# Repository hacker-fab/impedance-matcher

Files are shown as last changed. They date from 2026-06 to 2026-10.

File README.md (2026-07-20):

# Automated Impedance Matcher

Teensy 4.1 control loop firmware, custom PCB/CAD hardware, and Python telemetry logging/plotting tools.

## Layout

```
├── firmware/
│   ├── impedance_matcher/                 # Tuning loop, local UI, & motor controls
│   ├── headless_matcher/                  # Serial-only sketch
│   ├── live.py                            # Serial reader, live plots, CSV logger
│   └── plot.py                            # Offline plots & Mermaid export
└── hardware/
    ├── CAD/                               # Mechanical design & enclosure models
    └── PCB/                               # KiCad project & manufacturing files
        ├── impedance_matcher.kicad_pro    # KiCad project main file
        ├── spice/                         # SPICE verification of analog support circuits
        └── production/                    # JLCPCB manufacturing & assembly
            ├── imp_match.zip              # Gerbers
            ├── imp_match_bom.csv          # SMT BOM
            └── imp_match_positions.csv    # SMT CPL
```

**Arduino libraries:** Adafruit SSD1306, Adafruit GFX, and TMCStepper (GUI build); TMCStepper only for headless.

## Firmware

- **GUI:** Gradient-style matching toward lower VSWR; loop runs matching, encoder poll, then OLED refresh.
- **Headless:** Same matching; control via serial (`stream on`, `help`, etc.).

Serial is **500000** baud unless you change it in code and in `live.py`.

## Live telemetry

- Default CSV path is `data/csv/latest.csv`.
- Enable **`VSWR_CSV`** lines from the device: **USB log** in settings, or `stream on` in headless.

```bash
# From repo root; adjust --port to your Teensy
python firmware/live.py --port /dev/cu.usbmodemXXXX --window-seconds 20
```

## Offline plots

- Loads the 8-column telemetry CSV, drops bad/outlier rows, then plots VSWR, motors, and match state.
- **Matplotlib** is the default windowed plot.
- **Plotly:** `--interactive` (browser) or `--html`.
- **Mermaid:** `--mermaid` writes `data/mermaid/<csv_stem>_{vswr,motor1,motor2,match}.mmd`.
```bash
python firmware/plot.py path/to/run.csv
python firmware/plot.py path/to/run.csv --minutes --sample-interval 0.25
python firmware/plot.py path/to/run.csv --interactive
python firmware/plot.py path/to/run.csv --html
python firmware/plot.py path/to/run.csv --mermaid
```

## Telemetry CSV format

Written by `live.py` (and compatible with `plot.py`):

`host_time_s,device_millis,vswr,forward_v,reverse_v,motor1_pos_rad,motor2_pos_rad,at_match`

## Hardware notes

The analog support circuits (SWR sensing, input protection) were checked in ngspice.
See `hardware/PCB/spice/` for results and testbenches.

## Authors

- Miguel Salvacion
- William Gao

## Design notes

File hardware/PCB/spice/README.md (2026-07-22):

# SPICE Verification

ngspice checks on the board's analog support circuits: the SWR sense chain, the
input protection, and the 5 V -> 18 V -> 12 V power rail (DC). MCU, steppers,
OLED, fan, and opto are not simulated.

SWR path: `FWD_IN -> U1A buffer -> R10 2.7k / R13 1k divider -> ADC`, gain x0.27027
(TLV2372 on 12 V rail). REV path is identical (U1B, R11/R12).

## Results

### SWR -> ADC ceiling
Worst case is the buffer saturating near the 12 V rail. Ceiling lands at ~3.24 V
across every model, ~55 mV under the 3.3 V full scale. No clipping.

| Model | Ceiling  |
|---|---|
| Ideal buffer | 3.230 V  |
| Real TLV2372 macromodel | 3.243 V  |
| + PCB trace parasitics | 3.241 V  |

### Resistor tolerance (1% parts)
Worst-case divider ratio is +/-1.0% (R13 contributes (1-k)*1% = 0.73%, R10
contributes k*1% = 0.27%) -> ceiling ~3.27 V, still under 3.3 V.

### Protection
- Gate clamp (CR1 BZX84C5V6): off below 5 V; breaks down at 5.5 V and holds Vgs
  near -5.6 V up to 16 V input. Without it the gate would see -16 V.
- Reverse polarity (DMP6180 P-FET): reverse input blocked (rail ~nV, ~pA). Forward
  conducts with ~5 mV drop, ~120 mA at 12 V.

### PCB parasitics
SWR trace resistance is 0.05 - 0.10 ohm, via inductance ~0.7 nH (irrelevant at DC).
Shifts the ceiling by ~2.4 mV.

### SWR input protection
Each input has a 1k series resistor (R14/R15) plus clamp diodes to VCC/GND
(D2 BAV99S). This caps the TLV2372 input current on a fault, since
`I_clamp ~= (Vfault - Vrail - Vf) / 1k`. Abs-max is +/-10 mA.

| Fault on `FWD_IN` | unprotected | with R + clamp | vs +/-10 mA |
|---|---|---|---|
| 18 V | 1.02 A | 5.2 mA | safe |
| 30 V | 3.41 A | 17.1 mA | still over  |
| -5 V | 0.82 A | 4.2 mA | safe |

Normal operation is unaffected (8 V in -> 8.00 V pin) since the input draws no
DC. 30 V would need 2.2k (~7.9 mA).

### Power rail, DC
Rail is `5 V (USB) -> MT3608 boost -> ~17.5 V -> L7812 -> 12 V`. DC operating point
only; MT3608 switching ripple is out of scope.

- **LDO** (`ldo_reg.cir`): 18 -> 12 V holds 12.00 V across 0 - 1.2 A. `Pd =
  (Vin-Vout)*Iload` = 7.2 W at 1.2 A -- needs a heatsink (bare TO-220 ~2 W).
- **Chain** (`rail_chain_dc.cir`): `5 -> 17.51 -> 12.00 V` (R8 62k / R7 2.2k set the
  boost setpoint), lands 12.00 V on the TLV2372 VCC pin; SWR ADC reads 2.16 V for
  8 V `FWD_IN`.

Caveat: `l7812.lib` is behavioral (fixed 2 V dropout, no current limit); above
1.5 A is un-modeled.

## Testbenches

Run from this folder with `ngspice -b <file>.cir`. Batch mode writes sweep data to
the `.txt`/`.out` each file names (`wrdata`); DC-point benches `print` to stdout.

Install ngspice, or use the `ngspice` in KiCad's `bin/`. Results here are from
ngspice-46 (KiCad 10.0).

| File | Tests |
|---|---|
| `swr_opamp_chain.cir` | SWR buffer + divider sweep (ideal op-amp) |
| `opamp_fidelity.cir` | Same chain, real TLV2372 macromodel |
| `parasitic_ceiling.cir` | Chain with extracted PCB trace parasitics |
| `prot_gateclamp.cir` | Zener gate clamp sweep |
| `prot_revpol2.cir` | Reverse-polarity P-FET blocking + forward drop |
| `opamp_input_ov.cir` | SWR input overvoltage, pin clamp current |
| `opamp_input_protect.cir` | Series R + clamp fix, fault current <10mA |
| `ldo_reg.cir` | L7812 18->12V regulation, dropout, dissipation |
| `rail_chain_dc.cir` | End-to-end 5->18->12V DC, TLV2372 VCC |
| `l7812.lib` | L7812 behavioral reg model (included above) |
| `tlv2372.lib` | TLV2372 op-amp macromodel (included above) |

Outputs (`.txt`, `.out`, `.log`) are gitignored; re-run to regenerate.

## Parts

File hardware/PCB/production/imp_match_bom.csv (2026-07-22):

Designator | Footprint | Quantity | Value | LCSC Part #
A1 | TEENSY_LONG_EXT | 1 | TEENSY_4.1
C1, C2 | CAPC2012X110 | 2 | 22u | C45783
C10, C7, C8, C9 | CAPC2012X110 | 4 | 330n | C1740
C3, C4 | CAPPRD508W65D1000H1100B | 2 | 100u
CR1 | SOT95P240X110-3N | 1 | BZX84C5V6 | C148101
D1 | SMB_ONS | 1 | SS34 | C8678
D2 | SOT-363_SC-70-6 | 1 | BAV99S
DRIVER1, DRIVER2 | MODULE_TMC2209_SILENTSTEPSTICK | 2 | TMC2209_SILENTSTEPSTICK
FAN1, OLED1 | B4B-XH-A | 2 | Conn_01x04
FB1, FB2, FB3 | 0805 | 3 | FerriteBead | C15957
I2C1 | B2B-XH-A | 1 | Conn_01x02
L1 | INDM5450X580 | 1 | 22u | C9391
MOTOR1, MOTOR2 | JST-4-PTH-VERT | 2 | Conn_01x04
POWER1, TRANSMIT1 | 1X02_2.54_SCREWTERM | 2 | Conn_01x02
Q1 | DIP762W50P254L650H455Q4B | 1 | PC817 | C20612593
R1 | RESC2012X65 | 1 | 470 | C17710
R10, R11 | RESC2012X65 | 2 | 2.7k | C17530
R12, R13, R14, R15 | RESC2012X65 | 4 | 1k | C17513
R2, R5, R7 | RESC2012X65 | 3 | 2.2k | C17520
R3, R4, R6 | RESC2012X65 | 3 | 100k | C149504
R8 | RESC2012X65 | 1 | 62k | C17783
R9 | RESC2012X65 | 1 | 10k | C17414
REV_POLARITY1 | TO252_DMP6180SK3_DIO | 1 | DMP6180SK3-13TO252_DMP6180SK3_DIO | C93034
ROTARY1 | JST_B5B-XH-A | 1 | Conn_01x05
STEP_DOWN1 | TO-220-3 | 1 | L7812CV | C105651
STEP_UP0 | SOT95P280X145-6N | 1 | MT3608 | C84817
SWR1 | B3B-XH-A | 1 | JST_03
U1 | DIP794W45P254L959H508Q8 | 1 | TLV2372IP | C2878991

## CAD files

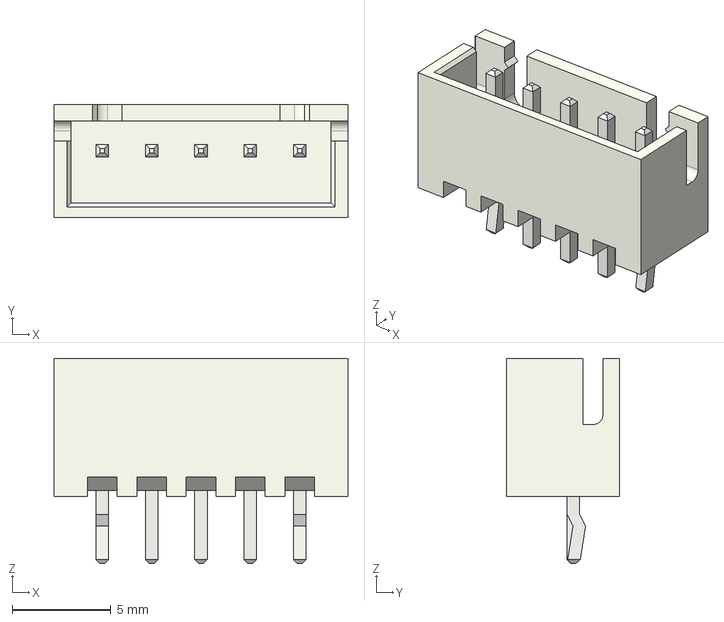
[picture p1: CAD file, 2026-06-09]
hardware/PCB/3dmodels/JST_XH_B5B-XH-A_1x05_P2.50mm_Vertical.step
14.9 x 5.75 x 10.4 mm

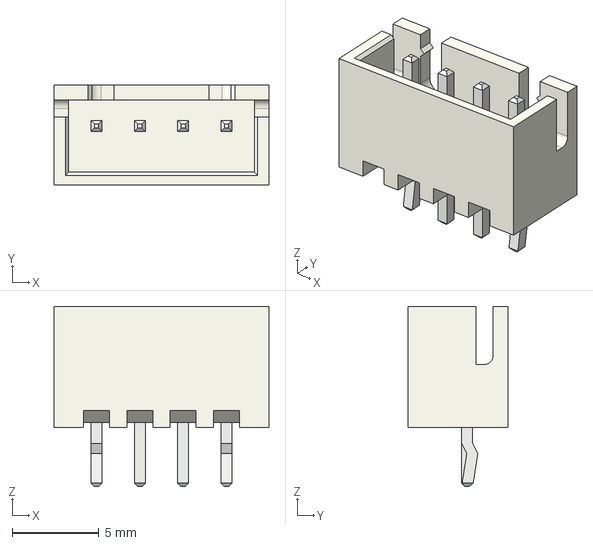
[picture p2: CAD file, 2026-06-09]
hardware/PCB/3dmodels/JST_XH_B4B-XH-A_1x04_P2.50mm_Vertical.step
12.4 x 5.75 x 10.4 mm

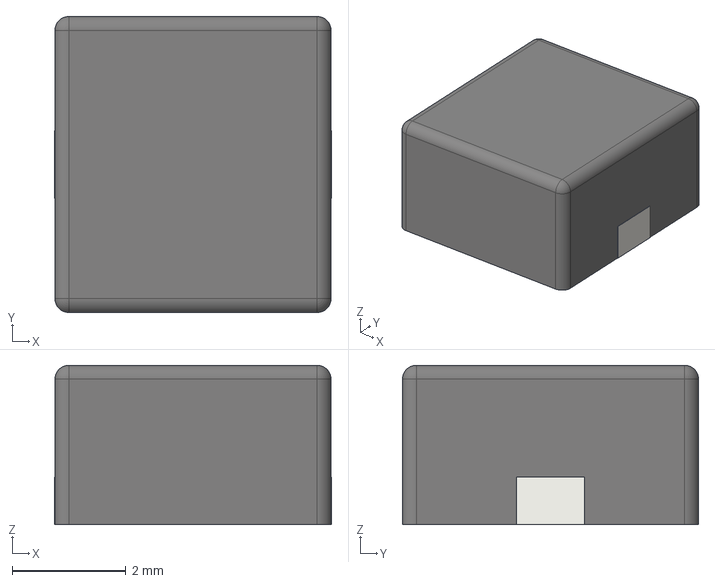
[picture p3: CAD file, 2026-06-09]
hardware/PCB/3dmodels/L_Changjiang_FXL0530.step
4.87 x 5.20 x 2.80 mm

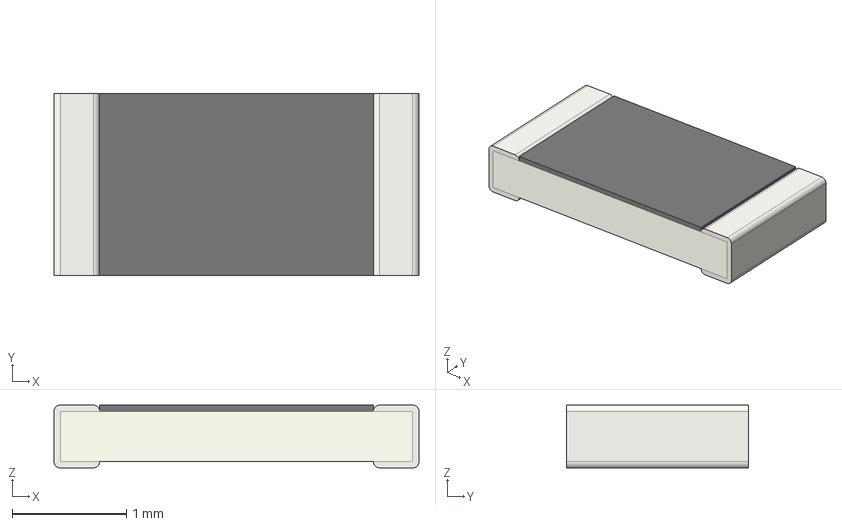
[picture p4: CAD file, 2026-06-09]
hardware/PCB/3dmodels/R_1206_3216Metric.step
3.20 x 1.60 x 0.55 mm

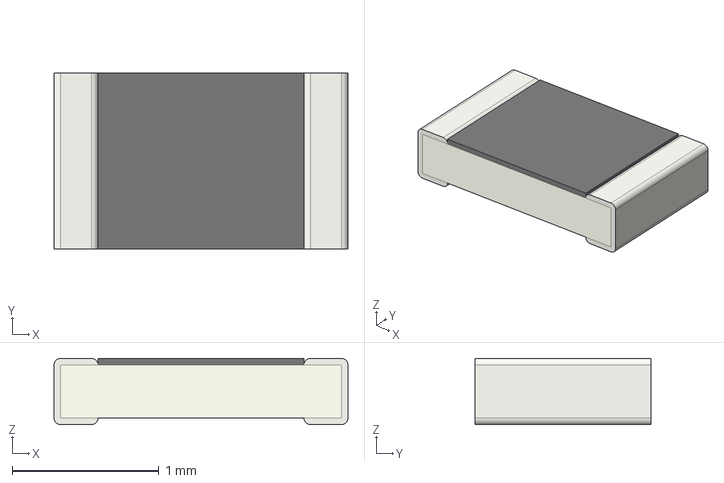
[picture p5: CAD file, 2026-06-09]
hardware/PCB/3dmodels/R_0805_2012Metric.step
2.00 x 1.20 x 0.45 mm

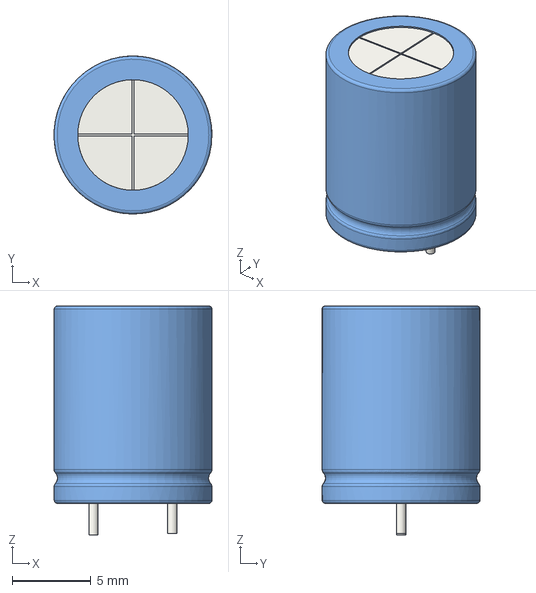
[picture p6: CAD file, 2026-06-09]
hardware/PCB/3dmodels/C_Radial_D10.0mm_H12.5mm_P5.00mm.step
10.00 x 10.00 x 14.5 mm

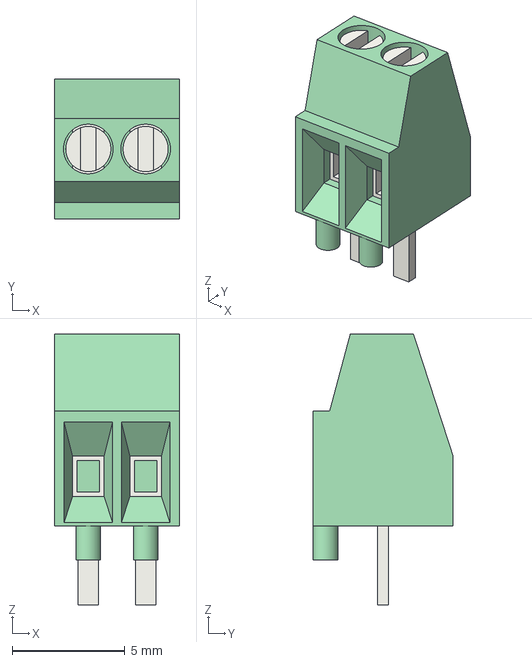
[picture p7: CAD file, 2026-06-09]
hardware/PCB/3dmodels/TerminalBlock_Phoenix_MPT-0,5-2-2.54_1x02_P2.54mm_Horizontal.step
5.54 x 6.20 x 12.0 mm

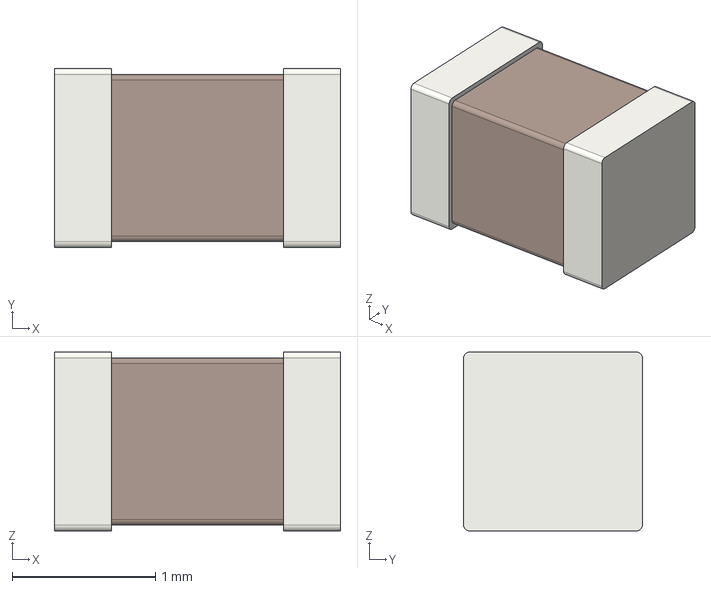
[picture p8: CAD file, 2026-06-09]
hardware/PCB/3dmodels/C_0805_2012Metric.step
2.00 x 1.25 x 1.25 mm

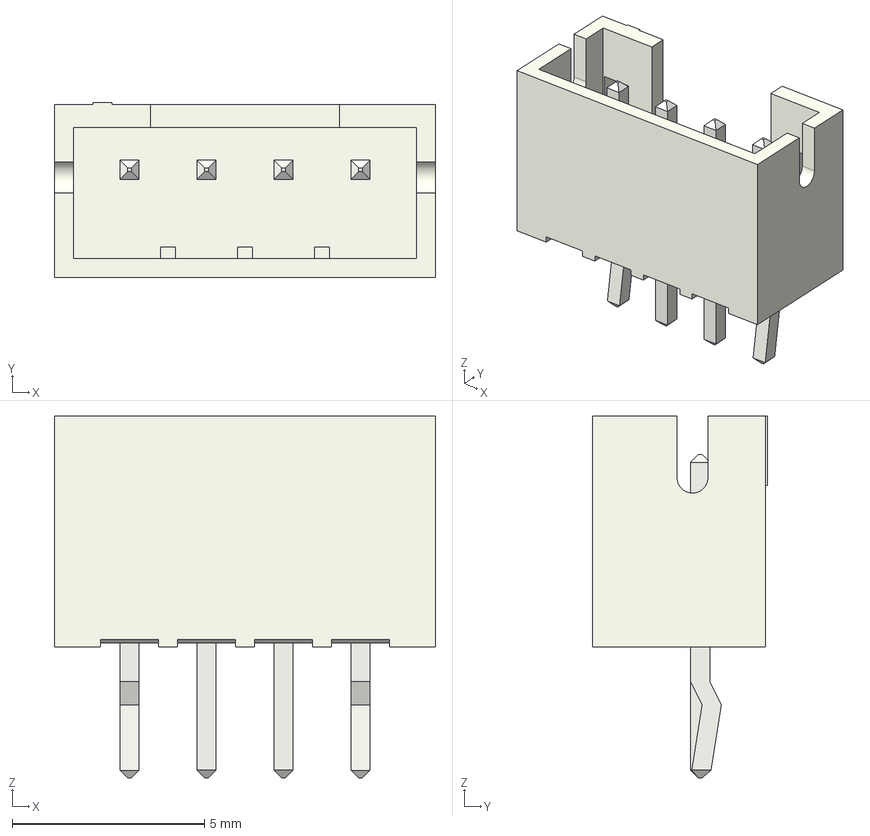
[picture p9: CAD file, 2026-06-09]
hardware/PCB/3dmodels/JST_PH_B4B-PH-K_1x04_P2.00mm_Vertical.step
9.90 x 4.55 x 9.40 mm

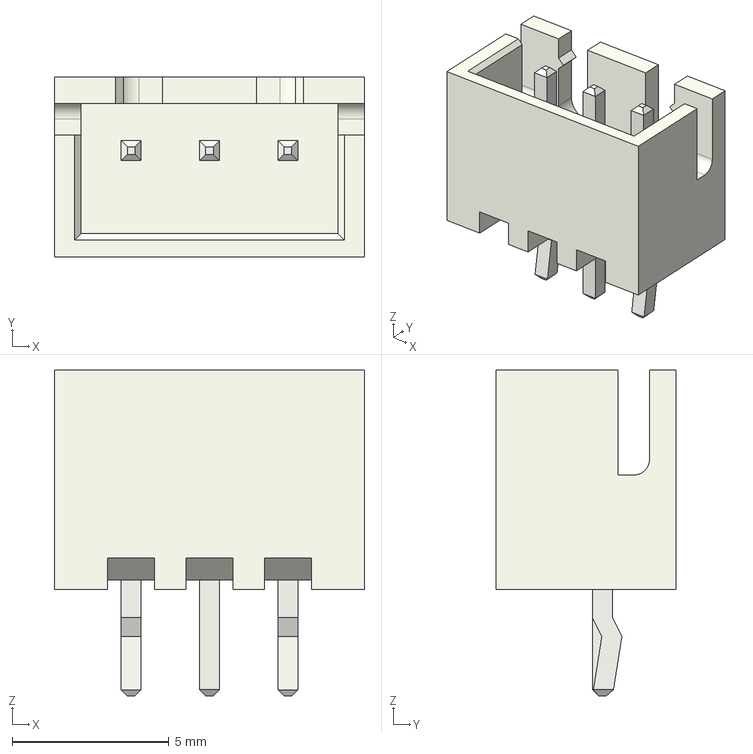
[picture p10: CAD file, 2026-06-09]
hardware/PCB/3dmodels/JST_XH_B3B-XH-A_1x03_P2.50mm_Vertical.step
9.90 x 5.75 x 10.4 mm

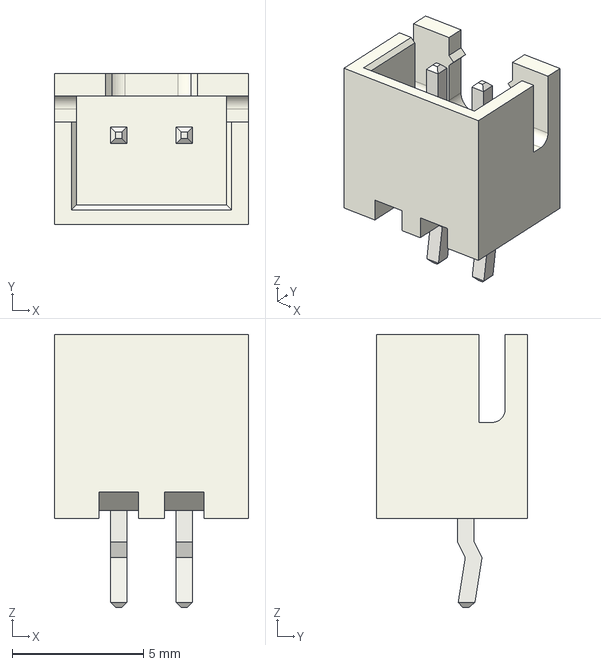
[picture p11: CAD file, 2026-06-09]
hardware/PCB/3dmodels/JST_XH_B2B-XH-A_1x02_P2.50mm_Vertical.step
7.40 x 5.75 x 10.4 mm

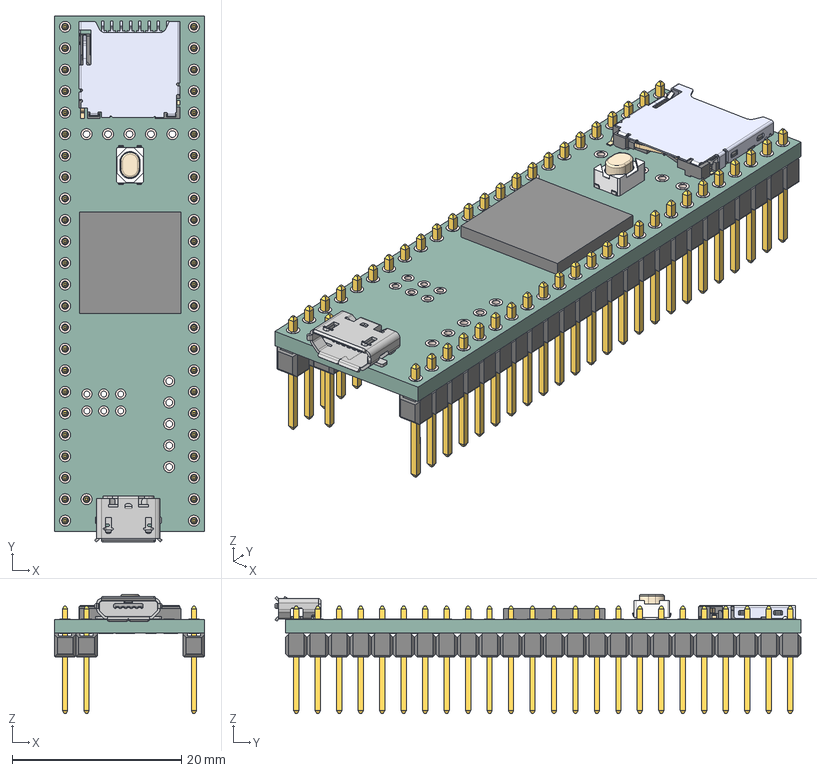
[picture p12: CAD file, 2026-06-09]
hardware/PCB/3dmodels/Teensy+4.stp
17.8 x 62.2 x 14.1 mm
114-00841-68--3DModel-STEP-56544
MIMXRT1052CVJ5B
MicroUSB Molex 473460001
Pin Header 1x6 TH Pitch 2.54mm x 4
Pin Header 1x6 TH Pitch 2.54mm v1(Mirror) x 4
Pin Header 1x1 TH Pitch 2.54mm
PTS810 SJK 250 SMTR LFS

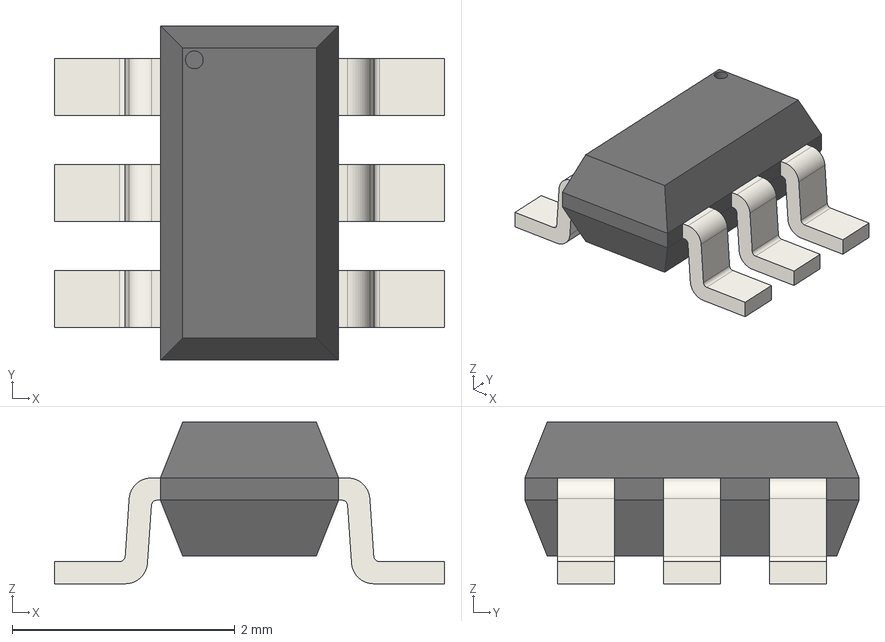
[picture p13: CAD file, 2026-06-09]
hardware/PCB/3dmodels/SOT95P280X145-6N.stp
3.50 x 3.00 x 1.45 mm

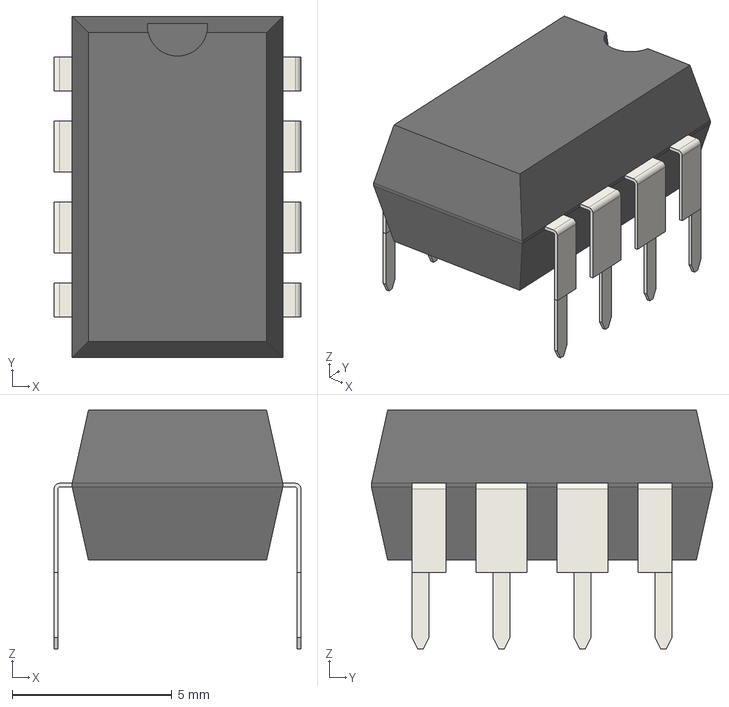
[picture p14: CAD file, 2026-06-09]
hardware/PCB/3dmodels/DIP794W45P254L959H508Q8.stp
7.74 x 10.7 x 7.48 mm

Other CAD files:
hardware/PCB/3dmodels/SOT95P240X110-3N.stp
hardware/PCB/3dmodels/SMB_ONS.stp
hardware/PCB/3dmodels/SS34.stp
hardware/PCB/3dmodels/TMC2209.stp
hardware/PCB/3dmodels/DIP762W50P254L650H455Q4B.stp
hardware/PCB/3dmodels/DMP6180SK3-13.stp
hardware/PCB/3dmodels/L7812CV.stp

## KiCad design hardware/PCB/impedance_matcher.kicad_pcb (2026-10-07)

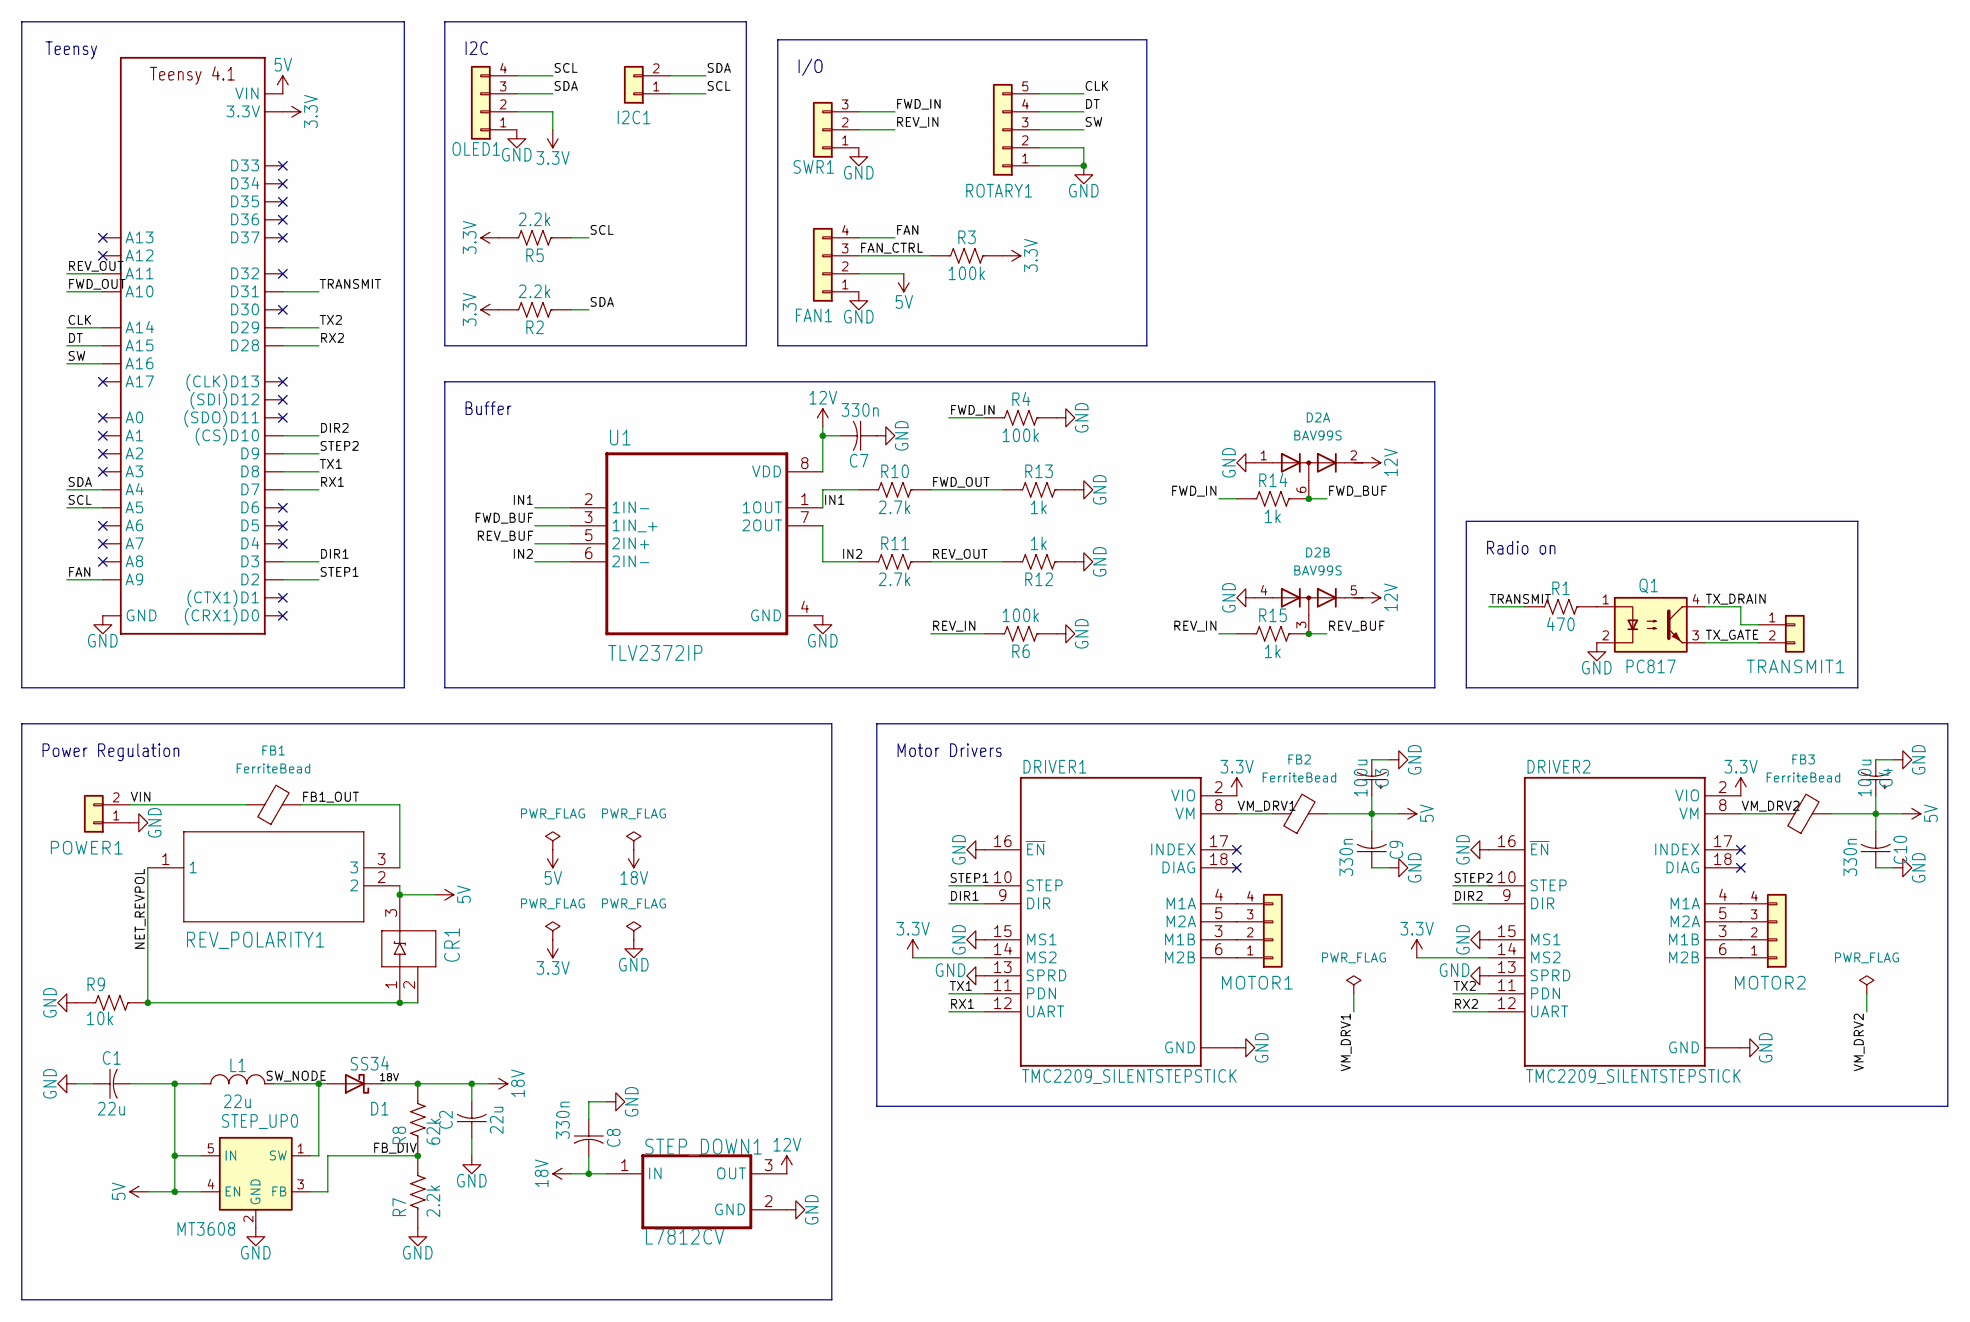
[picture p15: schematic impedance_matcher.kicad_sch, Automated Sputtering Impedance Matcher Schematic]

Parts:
A1: TEENSY_4.1; TEENSY_LONG_EXT
C1, C2: 22u; CAPC2012X110; MPN CL21A226MAQNNNE; LCSC Part C45783
C3, C4: 100u; CAPPRD508W65D1000H1100B
C7, C8, C9, C10: 330n; CAPC2012X110; MPN 0805B334K500NT; LCSC Part C1740
CR1: BZX84C5V6; SOT95P240X110-3N; MPN BZX84C5V6; LCSC Part C148101
D1: SS34; SMB_ONS; MPN SS34; LCSC Part C8678
D2: BAV99S; SOT-363_SC-70-6
DRIVER1, DRIVER2: TMC2209_SILENTSTEPSTICK; MODULE_TMC2209_SILENTSTEPSTICK
FAN1: Conn_01x04; JST_PH_B4B-PH-K_1x04_P2.00mm_Vertical
FB1, FB2, FB3: FerriteBead; L_0805_2012Metric; MPN MPZ2012S101AT000; LCSC Part C15957
I2C1: Conn_01x02; JST_PH_B2B-PH-K_1x02_P2.00mm_Vertical
L1: 22u; INDM5450X580; MPN SMNR5040-220MT; LCSC Part C9391
MOTOR1, MOTOR2: Conn_01x04; JST-4-PTH-VERT
OLED1: Conn_01x04; JST_PH_B4B-PH-K_1x04_P2.00mm_Vertical
POWER1: Conn_01x02; 1X02_2.54_SCREWTERM
Q1: PC817; DIP762W50P254L650H455Q4B; MPN PC817B; LCSC Part C20612593
R1: 470; RESC2012X65; MPN 0805W8F4700T5E; LCSC Part C17710
R2, R5, R7: 2.2k; RESC2012X65; MPN 0805W8F2201T5E; LCSC Part C17520
R3, R4, R6: 100k; RESC2012X65; MPN 0805W8F1003T5E; LCSC Part C149504
R8: 62k; RESC2012X65; MPN 0805W8F6202T5E; LCSC Part C17783
R9: 10k; RESC2012X65; MPN 0805W8F1002T5E; LCSC Part C17414
R10, R11: 2.7k; RESC2012X65; MPN 0805W8F2701T5E; LCSC Part C17530
R12, R13, R14, R15: 1k; RESC2012X65; MPN 0805W8F1001T5E; LCSC Part C17513
REV_POLARITY1: DMP6180SK3-13TO252_DMP6180SK3_DIO; TO252_DMP6180SK3_DIO; MPN DMP6180SK3-13; LCSC Part C93034
ROTARY1: Conn_01x05; JST_PH_B5B-PH-K_1x05_P2.00mm_Vertical
STEP_DOWN1: L7812CV; TO-220-3; MPN L7812CV; LCSC Part C105651
STEP_UP0: MT3608; SOT95P280X145-6N; MPN MT3608; LCSC Part C84817
SWR1: JST_03; JST_PH_B3B-PH-K_1x03_P2.00mm_Vertical
TRANSMIT1: Conn_01x02; 1X02_2.54_SCREWTERM
U1: TLV2372IP; DIP794W45P254L959H508Q8; MPN TLV2372IP; LCSC Part C2878991

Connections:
3.3V: A1.3V3 (3.3V), A1.3V3@2 (3.3V), DRIVER1.2 (VIO), DRIVER1.14 (MS2), DRIVER2.2 (VIO), DRIVER2.14 (MS2), OLED1.2, R2.2, R3.2, R5.2
5V: A1.VIN, C1.2, C3.1 (+), C4.1 (+), C9.2, C10.2, CR1.3, FAN1.2, FB2.2, FB3.2, L1.1, REV_POLARITY1.2, STEP_UP0.4 (EN), STEP_UP0.5 (IN)
12V: C7.2, D2.2 (K2), D2.5 (K4), STEP_DOWN1.3 (OUT), U1.8 (VDD)
18V: C2.2, C8.2, D1.1 (K), R8.2, STEP_DOWN1.1 (IN)
/CLK: A1.D38 (A14), ROTARY1.5
/DIR1: A1.D3, DRIVER1.9 (DIR)
/DIR2: A1.D10 ((CS)D10), DRIVER2.9 (DIR)
/DT: A1.D39 (A15), ROTARY1.4
/FAN: A1.D23 (A9), FAN1.4
/FAN_CTRL: FAN1.3, R3.1
/FB1_OUT: FB1.2, REV_POLARITY1.3
/FB_DIV: R7.2, R8.1, STEP_UP0.3 (FB)
/FWD_BUF: D2.6 (K3A4), R14.2, U1.3 (1IN_+)
/FWD_IN: R4.1, R14.1, SWR1.3
/FWD_OUT: A1.D24 (A10), R10.2, R13.1
/IN1: R10.1, U1.1 (1OUT), U1.2 (1IN-)
/IN2: R11.1, U1.6 (2IN-), U1.7 (2OUT)
/NET_REVPOL: CR1.1, CR1.2, R9.2, REV_POLARITY1.1
/REV_BUF: D2.3 (K1A2), R15.2, U1.5 (2IN+)
/REV_IN: R6.2, R15.1, SWR1.2
/REV_OUT: A1.D25 (A11), R11.2, R12.2
/RX1: A1.D7, DRIVER1.12 (UART)
/RX2: A1.D28, DRIVER2.12 (UART)
/SCL: A1.D19 (A5), I2C1.1, OLED1.4, R5.1
/SDA: A1.D18 (A4), I2C1.2, OLED1.3, R2.1
/STEP1: A1.D2, DRIVER1.10 (STEP)
/STEP2: A1.D9, DRIVER2.10 (STEP)
/SW: A1.D40 (A16), ROTARY1.3
/SW_NODE: D1.2 (A), L1.2, STEP_UP0.1 (SW)
/TRANSMIT: A1.D31, R1.1
/TX1: A1.D8, DRIVER1.11 (PDN)
/TX2: A1.D29, DRIVER2.11 (PDN)
/TX_DRAIN: Q1.4, TRANSMIT1.1
/TX_GATE: Q1.3, TRANSMIT1.2
/VIN: FB1.1, POWER1.2
/VM_DRV1: DRIVER1.8 (VM), FB2.1
/VM_DRV2: DRIVER2.8 (VM), FB3.1
GND: A1.AGND/GND (GND), A1.GND, A1.GND@2 (GND), C1.1, C2.1, C3.2 (-), C4.2 (-), C7.1, C8.1, C9.1, C10.1, D2.1 (A1), D2.4 (A3), DRIVER1.1 (GND), DRIVER1.7 (GND), DRIVER1.13 (SPRD), DRIVER1.15 (MS1), DRIVER1.16 (~EN), DRIVER2.1 (GND), DRIVER2.7 (GND), DRIVER2.13 (SPRD), DRIVER2.15 (MS1), DRIVER2.16 (~EN), FAN1.1, OLED1.1, POWER1.1, Q1.2, R4.2, R6.1, R7.1, R9.1, R12.1, R13.2, ROTARY1.1, ROTARY1.2, STEP_DOWN1.2 (GND), STEP_UP0.2 (GND), SWR1.1, U1.4 (GND)
unnamed: DRIVER1.4 (M1A), MOTOR1.4
unnamed: DRIVER1.3 (M1B), MOTOR1.2
unnamed: DRIVER1.5 (M2A), MOTOR1.3
unnamed: DRIVER1.6 (M2B), MOTOR1.1
unnamed: DRIVER2.4 (M1A), MOTOR2.4
unnamed: DRIVER2.3 (M1B), MOTOR2.2
unnamed: DRIVER2.5 (M2A), MOTOR2.3
unnamed: DRIVER2.6 (M2B), MOTOR2.1
unnamed: Q1.1, R1.2

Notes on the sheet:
I2C
Motor Drivers
Power Regulation
Radio on
I/O
Teensy
Buffer

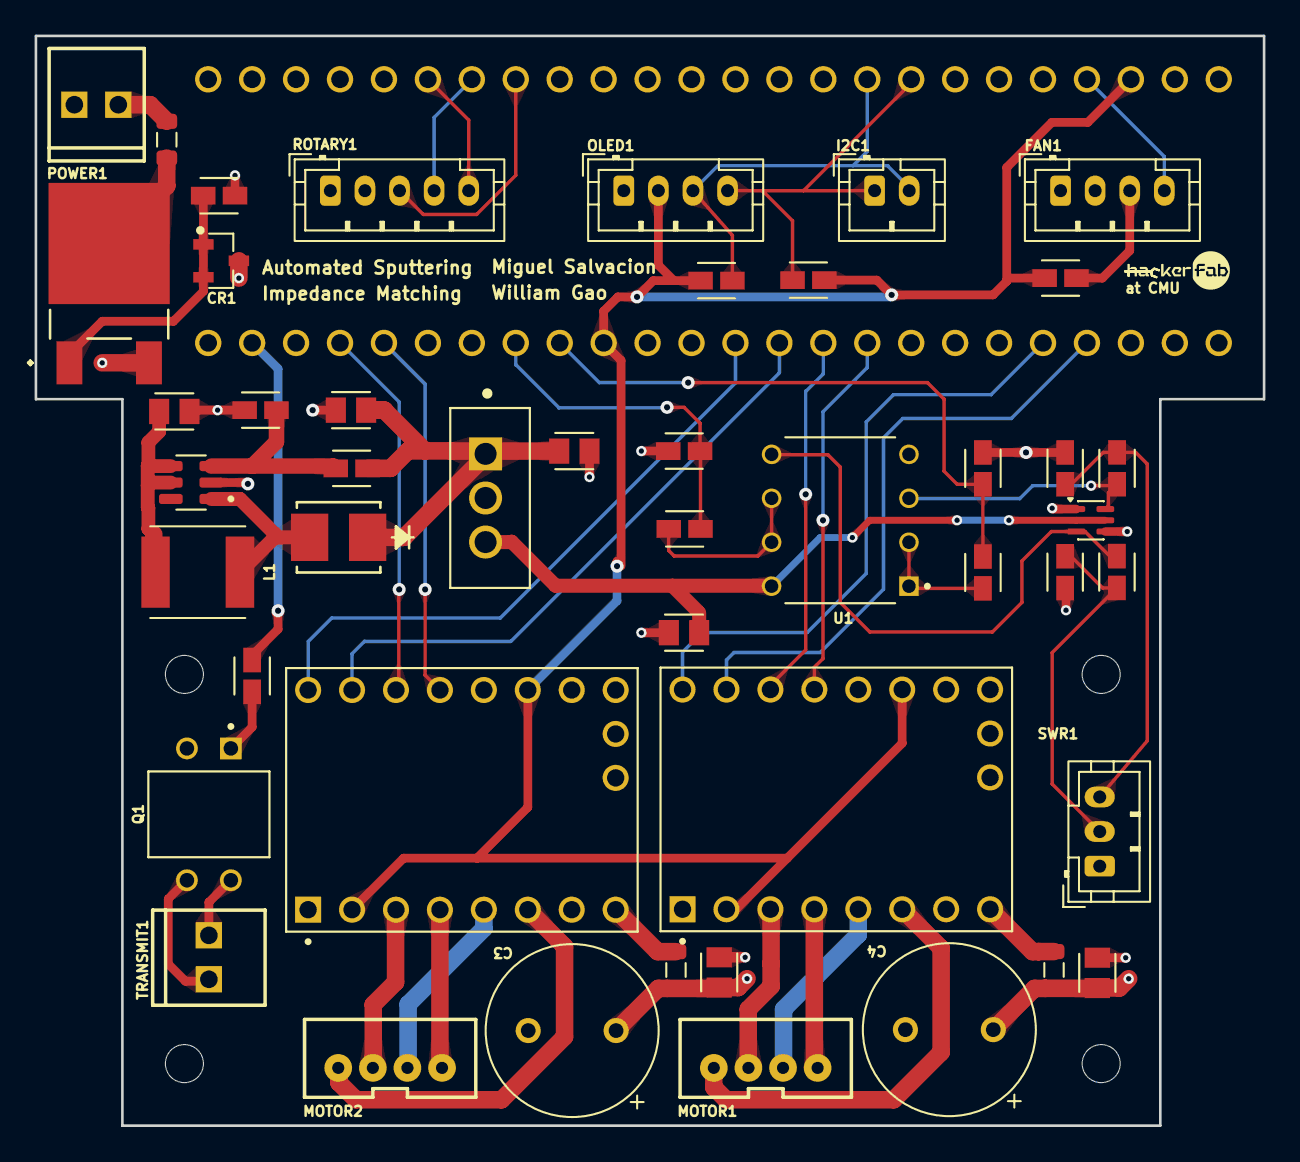
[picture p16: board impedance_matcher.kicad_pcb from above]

Board: 4 copper layers, 71.0 x 63.0 mm, 47 parts (1 on the bottom side), 47 nets.

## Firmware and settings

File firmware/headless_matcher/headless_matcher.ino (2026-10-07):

/*
 * headless_matcher.ino
 * Headless Matcher
 *
 * Dependencies (Arduino Library Manager):
 *   TMCStepper
 */

#include <Arduino.h>
#include <TMCStepper.h>
#include <stdlib.h>
#include <string.h>
#include <strings.h>

#include "../shared/matcher_core.h"

TMC2209Stepper driver1(&MATCHING_SERIAL_PORT, R_SENSE, DRV_ADDRESS_1);
TMC2209Stepper driver2(&MATCHING_SERIAL_PORT, R_SENSE, DRV_ADDRESS_2);

#define SCHED_LOOP_MS 16u

enum OpMode { MODE_AUTO, MODE_MANUAL };
OpMode opMode = MODE_AUTO;
bool radioTX = false;
bool atMatch = false;

float motor1Rad = 0.0f;
float motor2Rad = 0.0f;
float lossGrad1 = 0.1f;
float lossGrad2 = 0.1f;

long motor1Deg = 0;
long motor2Deg = 0;

float lastVSWR = 1.0f;
float lastFwdV = 0.0f;
float lastRevV = 0.0f;
static uint32_t lastStatusMs = 0;
bool csvStreamEnabled = false;

static void printHelp();
static void printStatus();
static void processSerialCommand();
static void handleCommand(char *line);
static void setRadioTX(bool enabled);
static void syncMotorDeg();
static bool parseLongArg(const char *arg, long *out);
static void setMotor1Step(long posDeg);
static void setMotor2Step(long posDeg);

void setup() {
  analogReadResolution(12);

  Serial.begin(CONTROL_BAUD);
  while (!Serial && millis() < 3000) {
  }

  pinMode(STEP_PIN_1, OUTPUT);
  pinMode(DIR_PIN_1, OUTPUT);
  pinMode(STEP_PIN_2, OUTPUT);
  pinMode(DIR_PIN_2, OUTPUT);
  pinMode(TRANSMIT_PIN, OUTPUT);
  digitalWrite(TRANSMIT_PIN, LOW);  // HIGH = TX on

  MATCHING_SERIAL_PORT.begin(MATCHING_UART_BAUD, SERIAL_8N1);
  delay(500);

  Serial.println("Starting Homing Sequence...");
  runHomingSequence();
  Serial.println("Finished Homing Sequence...");

  syncMotorDeg();
  printHelp();
  printStatus();
}

void loop() {
  processSerialCommand();

  if (opMode == MODE_AUTO) {
    autoMatchStep(lossGrad1, lossGrad2);
  } else {
    // Keep telemetry fresh in manual mode too
    measureLoss(FWD_PIN, REV_PIN);
  }

  syncMotorDeg();

  const bool statusPeriodically = !csvStreamEnabled;
  if (statusPeriodically && millis() - lastStatusMs >= 1000u) {
    lastStatusMs = millis();
    printStatus();
  }

  delay(SCHED_LOOP_MS);
}

static void processSerialCommand() {
  static char line[64];
  static size_t len = 0;

  while (Serial.available() > 0) {
    char c = (char)Serial.read();
    if (c == '\r' || c == '\n') {
      if (len > 0) {
        line[len] = '\0';
        handleCommand(line);
        len = 0;
      }
      continue;
    }
    if (len + 1 < sizeof(line)) {
      line[len++] = c;
    }
  }
}

static void handleCommand(char *line) {
  char *cmd = strtok(line, " \t");
  if (!cmd) return;

  if (strcasecmp(cmd, "help") == 0 || strcmp(cmd, "?") == 0) {
    printHelp();
    return;
  }
  if (strcasecmp(cmd, "mode") == 0) {
    char *arg = strtok(nullptr, " \t");
    if (!arg) {
      Serial.println("ERR mode needs: auto|manual");
      return;
    }
    if (strcasecmp(arg, "auto") == 0) {
      opMode = MODE_AUTO;
      Serial.println("OK mode=auto");
      return;
    }
    if (strcasecmp(arg, "manual") == 0) {
      opMode = MODE_MANUAL;
      Serial.println("OK mode=manual");
      return;
    }
    Serial.println("ERR mode must be auto|manual");
    return;
  }
  if (strcasecmp(cmd, "tx") == 0) {
    char *arg = strtok(nullptr, " \t");
    if (!arg) {
      Serial.println("ERR tx needs: on|off");
      return;
    }
    if (strcasecmp(arg, "on") == 0) {
      setRadioTX(true);
      Serial.println("OK tx=on");
      return;
    }
    if (strcasecmp(arg, "off") == 0) {
      setRadioTX(false);
      Serial.println("OK tx=off");
      return;
    }
    Serial.println("ERR tx must be on|off");
    return;
  }
  if (strcasecmp(cmd, "m1") == 0 || strcasecmp(cmd, "m2") == 0) {
    if (opMode != MODE_MANUAL) {
      Serial.println("ERR manual mode required for motor set");
      return;
    }
    char *arg = strtok(nullptr, " \t");
    long deg = 0;
    if (!parseLongArg(arg, &deg)) {
      Serial.println("ERR motor command needs angle 0..180");
      return;
    }
    deg = constrain(deg, (long)MOTOR_MIN_DEG, (long)MOTOR_MAX_DEG);
    if (strcasecmp(cmd, "m1") == 0) setMotor1Step(deg);
    else setMotor2Step(deg);
    syncMotorDeg();
    Serial.println("OK motor updated");
    return;
  }
  if (strcasecmp(cmd, "home") == 0) {
    Serial.println("Re-homing...");
    runHomingSequence();
    syncMotorDeg();
    Serial.println("OK homed");
    return;
  }
  if (strcasecmp(cmd, "stream") == 0) {
    char *arg = strtok(nullptr, " \t");
    if (!arg) {
      Serial.println("ERR stream needs: on|off");
      return;
    }
    if (strcasecmp(arg, "on") == 0) {
      csvStreamEnabled = true;
      Serial.println("OK stream=on");
      return;
    }
    if (strcasecmp(arg, "off") == 0) {
      csvStreamEnabled = false;
      Serial.println("OK stream=off");
      return;
    }
    Serial.println("ERR stream must be on|off");
    return;
  }
  Serial.println("ERR unknown command. Type: help");
}

static void printHelp() {
  Serial.println();
  Serial.println("Commands:");
  Serial.println("  help              - show commands");
  Serial.println("  mode auto|manual  - set operation mode");
  Serial.println("  tx on|off         - radio transmit switch");
  Serial.println("  m1 <deg>          - set motor 1 (manual only)");
  Serial.println("  m2 <deg>          - set motor 2 (manual only)");
  Serial.println("  home              - run homing sequence");
  Serial.println("  stream on|off     - VSWR_CSV lines for live.py / plot logging");
  Serial.println();
}

static void printStatus() {
  Serial.print("STATE mode=");
  Serial.print(opMode == MODE_AUTO ? "AUTO" : "MANUAL");
  Serial.print(" tx=");
  Serial.print(radioTX ? "ON" : "OFF");
  Serial.print(" atMatch=");
  Serial.print(atMatch ? "1" : "0");
  Serial.print(" m1_deg=");
  Serial.print(motor1Deg);
  Serial.print(" m2_deg=");
  Serial.print(motor2Deg);
  Serial.print(" vswr=");
  Serial.print(lastVSWR, 3);
  Serial.print(" fwdV=");
  Serial.print(lastFwdV, 3);
  Serial.print(" revV=");
  Serial.println(lastRevV, 3);
}

static void syncMotorDeg() {
  motor1Deg = clampDeg(motor1Rad);
  motor2Deg = clampDeg(motor2Rad);
}

static void setRadioTX(bool enabled) {
  radioTX = enabled;
  digitalWrite(TRANSMIT_PIN, enabled ? HIGH : LOW);
}

static bool parseLongArg(const char *arg, long *out) {
  if (!arg || !out) return false;
  char *end = nullptr;
  long parsed = strtol(arg, &end, 10);
  if (!end || *end != '\0') return false;
  *out = parsed;
  return true;
}

static void setMotor1Step(long posDeg) {
  setMotorStep(STEP_PIN_1, DIR_PIN_1, posDeg, motor1Rad);
}

static void setMotor2Step(long posDeg) {
  setMotorStep(STEP_PIN_2, DIR_PIN_2, posDeg, motor2Rad);
}

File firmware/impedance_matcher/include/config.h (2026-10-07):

#pragma once

// Pins
#define ENC_A        38
#define ENC_B        39
#define ENC_BTN      40
#define SCROLL_DIR   1  // +1 normal, -1 reversed
#define STEP_PIN_1   2
#define DIR_PIN_1    3
#define STEP_PIN_2   9
#define DIR_PIN_2    10
#define FWD_PIN      25
#define REV_PIN      24
#define TRANSMIT_PIN 31

// Comms
#define CONTROL_BAUD         500000    // USB serial to host (live.py / plot logging); keep in sync with telemetry.py BAUD
#define MATCHING_UART_BAUD   500000    // TMC2209 UART on Serial1
#define MATCHING_SERIAL_PORT Serial1

// Display
#define SCREEN_W 128
#define SCREEN_H 64

// Motion
#define MOTOR_MIN_DEG      0
#define MOTOR_MAX_DEG      180
#define MOTOR_STEP_SIZE    10
#define HOMING_BACKOFF_RAD (-PI)       // drive to hard stop
#define HOMING_CENTER_RAD  (PI / 2.0f) // re-center after homing

// Matching
#define VSWR_MATCH_ENTER 1.2f          // declare match below this; keep in sync with telemetry.py VSWR_MATCH
#define VSWR_MATCH_EXIT  1.4f          // drop match above this; keep in sync with telemetry.py VSWR_UNMATCH

// Scheduling/UI
#define DISPLAY_THROTTLE_AUTO_HOME_MS 300u
#define SCHED_UI_FRAME_MS             16u
#define SETTINGS_MENU_AFK_MS          15000u

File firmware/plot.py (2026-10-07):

#!/usr/bin/env python3
"""
plot.py
CSV VSWR plotter

Plot a saved VSWR telemetry CSV file

Expected format:

  host_time_s,device_millis,vswr,forward_v,reverse_v,motor1_pos_rad,motor2_pos_rad,at_match

Dependencies (pip):
  numpy, matplotlib, plotly
"""
from __future__ import annotations

import argparse
import csv
import os
import sys
from datetime import datetime, timedelta
from typing import Any, Dict, Tuple

import numpy as np

import telemetry

DATA_CSV_DIR = telemetry.DATA_CSV_DIR
DATA_HTML_DIR = os.path.join("data", "html")
DATA_MERMAID_DIR = os.path.join("data", "mermaid")

# Drop outliers (garbage data)
VSWR_MAX = telemetry.VSWR_MAX
MOTOR_MAX_ABS_RAD = float(np.pi)


def resolve_input_csv(path: str) -> str:
    """Use path if it exists; for a bare name (or ./name), try data/csv/name."""
    if os.path.isfile(path):
        return path
    name = os.path.basename(path)
    if name and (os.path.dirname(path) in ("", ".") or path == name):
        candidate = os.path.join(DATA_CSV_DIR, name)
        if os.path.isfile(candidate):
            return candidate
    return path


def resolve_html_output(html_arg: str | None, input_csv: str) -> str | None:
    """Map --html to a path; bare names and empty (auto) go under data/html/."""
    if html_arg is None:
        return None
    if html_arg == "":
        stem = os.path.splitext(os.path.basename(input_csv))[0]
        return os.path.join(DATA_HTML_DIR, f"{stem}.html")
    if os.path.isabs(html_arg) or os.path.dirname(html_arg):
        return html_arg
    return os.path.join(DATA_HTML_DIR, html_arg)


def resolve_mermaid_output(mermaid_arg: str | None, input_csv: str) -> str | None:
    """Map --mermaid to a path; bare names and empty (auto) go under data/mermaid/."""
    if mermaid_arg is None:
        return None
    if mermaid_arg == "":
        stem = os.path.splitext(os.path.basename(input_csv))[0]
        return os.path.join(DATA_MERMAID_DIR, f"{stem}.mmd")
    if os.path.isabs(mermaid_arg) or os.path.dirname(mermaid_arg):
        return mermaid_arg
    return os.path.join(DATA_MERMAID_DIR, mermaid_arg)


def _write_mermaid_series_chart(
    path: str,
    tx: np.ndarray,
    series: np.ndarray,
    series_label: str,
    y_axis_label: str | None,
    xlabel: str,
    title: str,
    y_axis_bounds: tuple[float, float] | None = None,
    render_mode: str = "line",
) -> None:
    """
    Write Mermaid xychart-beta code for one telemetry series.
    """
    if tx.size == 0:
        raise ValueError("Cannot write Mermaid chart with no samples.")

    def fmt_vals(arr: np.ndarray) -> list[str]:
        data = np.asarray(arr, dtype=np.float64).copy()
        if data.size == 0:
            return []
        finite = np.isfinite(data)
        if not finite.any():
            data[:] = 0.0
        else:
            first = int(np.argmax(finite))
            data[:first] = data[first]
            for i in range(first + 1, data.size):
                if not np.isfinite(data[i]):
                    data[i] = data[i - 1]
        return [f"{float(y):.3f}".rstrip("0").rstrip(".") for y in data]

    series_vals = fmt_vals(series)

    x_start = float(tx[0])
    x_end = float(tx[-1])
    if x_end <= x_start:
        x_end = x_start + 1.0
    finite_vals = np.asarray(series, dtype=np.float64)
    finite_vals = finite_vals[np.isfinite(finite_vals)]
    if finite_vals.size:
        y_min = float(np.min(finite_vals))
        y_max = float(np.max(finite_vals))
    else:
        y_min = 0.0
        y_max = 1.0
    if y_axis_bounds is None:
        y_lo = np.floor(y_min * 10.0) / 10.0
        y_hi = np.ceil(y_max * 10.0) / 10.0
        if y_hi <= y_lo:
            y_hi = y_lo + 1.0
    else:
        y_lo, y_hi = y_axis_bounds

    plot_stmt = "line" if render_mode == "line" else "bar"

    lines = [
        "xychart-beta",
        f'    title "{os.path.basename(title)} {series_label}"',
        f'    x-axis "{xlabel}" {x_start:g} --> {x_end:g}',
        f'    y-axis "{(y_axis_label or series_label)}" {y_lo:g} --> {y_hi:g}',
        f'    {plot_stmt} [{", ".join(series_vals)}]',
    ]

    parent = os.path.dirname(os.path.abspath(path))
    if parent:
        os.makedirs(parent, exist_ok=True)
    with open(path, "w", encoding="utf-8") as f:
        f.write("\n".join(lines) + "\n")


def _write_mermaid_match_gantt(
    path: str,
    tx: np.ndarray,
    matched: np.ndarray,
    title: str,
    *,
    time_unit: str,
) -> None:
    """Write Mermaid gantt code for match/no-match intervals."""
    if tx.size == 0 or matched.size == 0 or tx.size != matched.size:
        raise ValueError("Cannot write Mermaid match gantt with invalid sample arrays.")

    tm = np.asarray(tx, dtype=np.float64).copy()
    if time_unit == "seconds":
        tm = tm / 60.0

    state = np.asarray(matched >= 0.5, dtype=bool)
    change_idx = np.flatnonzero(np.diff(state.astype(np.int8)) != 0) + 1
    starts = np.concatenate(([0], change_idx))

    pos_steps = np.diff(tm)
    pos_steps = pos_steps[np.isfinite(pos_steps) & (pos_steps > 0)]
    min_step = float(np.min(pos_steps)) if pos_steps.size else 1.0

    def to_min_token(v: float) -> int:
        return int(np.floor(float(v)))

    base_dt = datetime(2000, 1, 1, 0, 0, 0)

    def fmt_dt(minute_offset: int) -> str:
        return (base_dt + timedelta(minutes=int(minute_offset))).strftime("%Y-%m-%d %H:%M")

    lines = [
        "%%{init: {'themeVariables': {"
        "'sectionBkgColor': '#ffffff00', "
        "'sectionBkgColor2': '#ffffff00', "
        "'sectionBorderColor': '#94a3b8', "
        "'taskBkgColor': '#2563eb', "
        "'taskBorderColor': '#1d4ed8', "
        "'activeTaskBkgColor': '#16a34a', "
        "'activeTaskBorderColor': '#15803d', "
        "'doneTaskBkgColor': '#64748b', "
        "'doneTaskBorderColor': '#475569', "
        "'critTaskBkgColor': '#dc2626', "
        "'critTaskBorderColor': '#b91c1c', "
        "'ganttSectionBkgColor': '#ffffff00', "
        "'ganttSectionBkgColor2': '#ffffff00', "
        "'ganttSectionBorderColor': '#94a3b8', "
        "'ganttTaskBkgColor': '#2563eb', "
        "'ganttTaskBorderColor': '#1d4ed8', "
        "'ganttActiveTaskBkgColor': '#16a34a', "
        "'ganttActiveTaskBorderColor': '#15803d', "
        "'ganttDoneTaskBkgColor': '#64748b', "
        "'ganttDoneTaskBorderColor': '#475569', "
        "'ganttCritTaskBkgColor': '#dc2626', "
        "'ganttCritTaskBorderColor': '#b91c1c', "
        "'lineColor': '#64748b'"
        "}}}%%",
        "gantt",
        f'    title {os.path.basename(title)} Match Timeline',
        "    dateFormat  YYYY-MM-DD HH:mm",
        "    axisFormat  %H:%M",
        "",
        "    section .",
    ]

    # Build a single monotonic boundary list so adjacent tasks do not overlap
    boundaries = [to_min_token(float(tm[starts[0]]))]
    if starts.size > 1:
        for idx in starts[1:]:
            boundaries.append(int(np.rint(float(tm[idx]))))
    boundaries.append(int(np.ceil(float(tm[-1]))))
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

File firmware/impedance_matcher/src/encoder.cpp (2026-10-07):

#include "../include/encoder.h"
#include "../include/config.h"

#include <Arduino.h>

// ISR on A and B (same handler)
static volatile int   encRaw    = 0;
static volatile uint8_t encLastAB = 0;

// Table gives ±1 per valid Gray step
static const int8_t kQuadTable[16] = {
    0, +1, -1, 0,
    -1, 0, 0, +1,
    +1, 0, 0, -1,
    0, -1, +1, 0,
};

static void encoderIsr() {
  uint8_t a    = (uint8_t)digitalRead(ENC_A);
  uint8_t b    = (uint8_t)digitalRead(ENC_B);
  uint8_t newAB = (uint8_t)((a << 1) | b);
  uint8_t idx   = (uint8_t)((encLastAB << 2) | newAB);
  int8_t step   = kQuadTable[idx];
  if (step != 0) {
    encRaw += step;
    encLastAB = newAB;
  }
}

// Typical mechanical detent
#define ENC_COUNTS_PER_CLICK 4

static int encAccum = 0;

// Button: FALLING counted in ISR
static volatile uint32_t btnFallEvents = 0;

static void btnFallIsr() {
  btnFallEvents++;
}

#define DEBOUNCE_MS 40
static uint32_t lastBtnAcceptMs = 0;

static int consumeDelta() {
  noInterrupts();
  int d = encRaw;
  encRaw = 0;
  interrupts();
  encAccum += d;
  int clicks = encAccum / ENC_COUNTS_PER_CLICK;
  encAccum -= clicks * ENC_COUNTS_PER_CLICK;
  return clicks * SCROLL_DIR;
}

static bool consumeButton() {
  uint32_t falls;
  noInterrupts();
  falls         = btnFallEvents;
  btnFallEvents = 0;
  interrupts();

  if (falls == 0) {
    return false;
  }

  uint32_t now = millis();
  if ((now - lastBtnAcceptMs) <= DEBOUNCE_MS) {
    noInterrupts();
    btnFallEvents += falls;
    interrupts();
    return false;
  }

  if (digitalRead(ENC_BTN) != LOW) {
    return false;
  }

  lastBtnAcceptMs = now;
  return true;
}

void encoder_init() {
  pinMode(ENC_A, INPUT_PULLUP);
  pinMode(ENC_B, INPUT_PULLUP);
  pinMode(ENC_BTN, INPUT_PULLUP);

  uint8_t a = (uint8_t)digitalRead(ENC_A);
  uint8_t b = (uint8_t)digitalRead(ENC_B);
  encLastAB = (uint8_t)((a << 1) | b);

  int pinA = digitalPinToInterrupt(ENC_A);
  int pinB = digitalPinToInterrupt(ENC_B);
  int pinT = digitalPinToInterrupt(ENC_BTN);
  attachInterrupt(pinA, encoderIsr, CHANGE);
  attachInterrupt(pinB, encoderIsr, CHANGE);
  attachInterrupt(pinT, btnFallIsr, FALLING);
}

void encoder_poll(int* outDelta, bool* outPressed) {
  *outDelta   = consumeDelta();
  *outPressed = consumeButton();
}

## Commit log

2026-04-30 Visualize csv data
    [vswr_log.csv]
2026-05-01 Reogranize repo and add PCB files
    [JLC_bom.csv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]
2026-06-09 KiCad files
    [impedance_matcher.kicad_pcb, impedance_matcher.kicad_sch]
2026-06-09 Small PCB fixes
    [impedance_matcher.kicad_pcb]
2026-06-09 Add some 3D models
    [DIP762W50P254L650H455Q4B.stp, DIP794W45P254L959H508Q8.stp, DMP6180SK3-13.stp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]
2026-06-09 More PCB fixes
    [impedance_matcher.kicad_pcb]
2026-06-09 All 3D models
    [C_0805_2012Metric.step, C_Radial_D10.0mm_H12.5mm_P5.00mm.step, JST_PH_B4B-PH-K_1x04_P2.00mm_Vertical.step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]
2026-06-09 New gerbers
    [C_0805_2012Metric.step, C_Radial_D10.0mm_H12.5mm_P5.00mm.step, DIP762W50P254L650H455Q4B.stp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]
2026-06-11 Move capacitor closer to op-amp VDD
    [impedance_matcher.kicad_pcb, impedance_matcher.kicad_sch]
2026-06-11 Switch to 4 layer PCB and add ferrite beads
    [imp_match_bom.csv, imp_match_designators.csv, imp_match_positions.csv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]
2026-06-15 Switch all resistors to 0805
    [imp_match_bom.csv, imp_match_positions.csv, impedance_matcher.kicad_pcb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]
2026-06-15 Small fixes
    [impedance_matcher.kicad_pcb]
2026-07-08 Hackerfab Logo
    [impedance_matcher.kicad_pcb]
2026-07-20 Clean up nets and layers
    [imp_match_bom.csv, impedance_matcher.kicad_pcb, impedance_matcher.kicad_sch]
2026-07-22 SWR input protection
    [imp_match_bom.csv, imp_match_designators.csv, imp_match_positions.csv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]
2026-07-22 Add stitching vias
    [impedance_matcher.kicad_pcb]
2026-09-15 change i2c1, rotary1, oled1, fan1, swr1 to JST PH 2.0mm and update C3/C4 pad1 to be 5V instead of pad2
    [impedance_matcher.kicad_pcb, impedance_matcher.kicad_sch]
2026-10-07 Fix traces and make more compact
    [impedance_matcher.kicad_pcb]
2026-10-07 Revert "Fix traces and make more compact"
    This reverts commit 96239e169e8d7fc6dc4d81f6383f1f882c301b51.
    [impedance_matcher.kicad_pcb]
2026-10-07 Make more compact
    [impedance_matcher.kicad_pcb]
2026-10-10 Correct driver UART, detector loading, and fan interface
2026-10-10 Correct sensing and stepping, add optional UART
2026-10-31 test: add PCB-firmware agreement checks
2026-11-12 hardware: add optional input fuse footprint

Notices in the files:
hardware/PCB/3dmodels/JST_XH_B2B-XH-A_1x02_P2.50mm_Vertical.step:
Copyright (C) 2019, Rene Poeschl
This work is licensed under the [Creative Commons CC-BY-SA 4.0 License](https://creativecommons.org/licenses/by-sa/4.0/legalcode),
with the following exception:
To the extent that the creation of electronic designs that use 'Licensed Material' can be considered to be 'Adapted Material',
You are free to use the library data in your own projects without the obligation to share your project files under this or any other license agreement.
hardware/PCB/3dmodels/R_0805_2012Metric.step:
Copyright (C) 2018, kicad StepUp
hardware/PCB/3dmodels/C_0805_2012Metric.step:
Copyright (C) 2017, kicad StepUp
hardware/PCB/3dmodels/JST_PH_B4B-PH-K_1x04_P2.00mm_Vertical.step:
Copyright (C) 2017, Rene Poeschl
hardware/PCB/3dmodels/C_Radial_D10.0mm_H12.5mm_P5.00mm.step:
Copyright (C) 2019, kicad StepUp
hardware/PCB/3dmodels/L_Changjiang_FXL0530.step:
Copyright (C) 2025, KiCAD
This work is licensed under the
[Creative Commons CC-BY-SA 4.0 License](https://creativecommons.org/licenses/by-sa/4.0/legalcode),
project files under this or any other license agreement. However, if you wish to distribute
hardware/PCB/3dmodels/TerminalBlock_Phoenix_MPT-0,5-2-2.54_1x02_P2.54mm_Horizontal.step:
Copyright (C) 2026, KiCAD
